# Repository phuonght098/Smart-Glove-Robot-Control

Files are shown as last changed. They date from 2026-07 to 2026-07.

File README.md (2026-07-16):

# Robotic Arm Control via Sensor Glove






✔ Real-time 5 DOF robotic arm teleoperation

✔ Quaternion-based motion estimation

✔ PCA-based automatic anatomical axis calibration

✔ Swing–Twist decomposition for joint angle extraction

✔ Adaptive ZUPT heading drift compensation

✔ ESP-NOW wireless communication

✔ Open-source hardware, firmware, PCB, and 3D models



# Table of Content
1. Introduction
2. Features
3. Hardware
4. Software
5. Getting Started
6. Results
7. Future Work
8. Contact
9. License

# 1. Introduction
This project focuses on the design and fabrication of a 5-degree-of-freedom (5 DOF) robotic arm equipped with a gripper, capable of imitating human arm movements in real-time. Tilt angles and motion data are acquired via a sensor glove equipped with the ICM20948 IMU module.

The project is developed with the aim of researching robotic applications in hazardous environments, enabling remote pick-and-place operations without direct physical intervention.

# 2. Features
🎯 Real-time Control: Low latency operation, accurately tracking and imitating human hand movements.

🧭 Digital Processing with DMP: Utilizes the ICM20948's onboard Digital Motion Processor to calculate Quaternions directly on the sensor, significantly reducing the processing load on the main microcontroller.

⚡ Power Optimization: Features a customized voltage divider circuit and optimized current consumption for better efficiency.

🛠️ Fully Open-source: Provides complete source code, PCB design files, and 3D printing models.

# 3. Hardware

## 3.1 Bill of Materials - BOM
Here is the list of main components used in this project.

| Component  | Qty | 
| :--- | ---: |
| ESP32 | 2 | 
| ICM20948 | 3 | 
| Servo MG996R | 3 | 
| Servo MG90S | 3 |
| PCA9685 | 1 |
| Flex Sensor | 1 |
| Resistor 4.7k | 2 |
| Resistor 10k | 1 |
| Resistor 100k | 1 |
| Resistor 200k | 1 |
| LED | 1 |
| Toggle Switch | 1 |
| Lipo 2s 420mAh | 1 |
| Mini360 | 1 |
| 5v 10A Battery | 1 |
| Ball Bearing 6806ZZ (30x42x7) | 1 |

📌 Note: For the mechanical structure, all .STL files required for 3D printing the robotic arm are provided in the /3D_Models directory.



## 3.2 Wiring & PCB
The schematic and PCB layout files, designed using EasyEDA.com, are located in the /Hardware folder. Due to the I2C address conflict among the ICM20948 sensors (which have a default address of 0x68), we need to connect the AD0 pin of each sensor to Vcc or GND to fix their addresses to either 0x68 or 0x69, as illustrated below.



Below is the wiring diagram of the sensor glove circuit.



A voltage divider circuit is implemented for the flex sensor to read the ADC value on pin D34 of the ESP32. When the flex sensor bends, its resistance changes, which in turn alters the voltage at the junction between the flex sensor and the 10k resistor.

Image of the sensor glove's PCB layout:



## 3.3 3D Printing
Recommended print settings:

Material: PLA / PETG

Infill: > 30%

Layer height: 0.2mm

# 4. Software

## 4.1 Overall System Flowchart
<details>
<summary>📊 System Flowchart</summary>

```mermaid
graph TD
  START([START]) --> INIT1[Initialize ESP32]
  INIT1 --> INIT2[Initialize I2C Bus]
  INIT2 --> INIT3[Initialize 3x ICM20948 IMUs]
  INIT3 --> INIT4[Initialize DMP Quaternion]
  INIT4 --> INIT5[Initialize ESP-NOW]
  INIT5 --> WAIT[Wait for DMP convergence 60s]
  WAIT --> COND{PCA Calibration?}
  
  COND -- Yes --> PCA[PCA Calibration]
  PCA --> ZERO[Zero Calibration]
  ZERO --> MAIN[Main Loop]
  
  COND -- No --> IDLE[Wait for Command]
  IDLE --> MAIN
  
  MAIN --> READ[Read Quaternions from 3 IMUs]
  READ --> SYNC[Synchronize Timestamps]
  SYNC --> NLERP[NLERP Filtering]
  NLERP --> ANAT[Convert to Anatomical Frame]
  ANAT --> CALC[Calculate Joint Angles S1-S5]
  CALC --> MAP[Map to Servo PWM]
  MAP --> SEND[Send via ESP-NOW]
  SEND --> EXEC[Robot Execution]
  EXEC --> READ
```

</details>

## 4.2 Flowchart PCA Calibration
This is the most unique core algorithm of the project for coordinate axis calibration.

<details>
<summary>📊 PCA Calibration </summary>

```mermaid
graph TD
  START([START PCA]) --> NPOSE[N-Pose Posture]
  NPOSE --> GRAV[Measure Gravity Vectors<br>gUpper, gForearm, gHand]
  GRAV --> PCA_S[Shoulder PCA <br> Shoulder Motion]
  PCA_S --> THU_S[Collect Quaternions for 3s]
  THU_S --> DELTA_S[Calculate ΔQuaternion]
  DELTA_S --> COV_S[Create Covariance Matrix]
  COV_S --> POW_S[Power Iteration]
  POW_S --> AXIS_S[Shoulder PCA Axis]
  
  AXIS_S --> PCA_E[Elbow PCA <br> Elbow Motion]
  PCA_E --> THU_E[Collect Quaternions for 3s]
  THU_E --> DELTA_E[Calculate ΔQuaternion]
  DELTA_E --> COV_E[Create Covariance Matrix]
  COV_E --> POW_E[Power Iteration]
  POW_E --> AXIS_E[Elbow PCA Axis]
  
  AXIS_E --> PCA_W[Wrist PCA <br> Wrist Motion]
  PCA_W --> THU_W[Collect Quaternions for 3s]
  THU_W --> DELTA_W[Calculate ΔQuaternion]
  DELTA_W --> COV_W[Create Covariance Matrix]
  COV_W --> POW_W[Power Iteration]
  POW_W --> AXIS_W[Wrist PCA Axis]
  
  AXIS_W --> GRAM[Gram-Schmidt Orthogonalization]
  GRAM --> MOUNT[Create Mount Quaternion]
  MOUNT --> SAVE[Save Q_Mount]
  SAVE --> END([END])
```
</details>

## 4.3 Quaternion Processing Pipeline
This is the main continuous data processing pipeline in the system loop.

<details>
<summary>📊 Quaternion Processing Pipeline </summary>

```mermaid
graph TD
  Q1[/Quaternion Upper/] --> SYNC[Time Synchronization]
  Q2[/Quaternion Forearm/] --> SYNC
  Q3[/Quaternion Hand/] --> SYNC
  
  SYNC --> NLERP[NLERP Filter]
  NLERP --> F1[Q_Upper_Filtered]
  NLERP --> F2[Q_Forearm_Filtered]
  NLERP --> F3[Q_Hand_Filtered]
  
  F1 --> MOUNT[Mount Calibration]
  F2 --> MOUNT
  F3 --> MOUNT
  
  MOUNT --> ANAT[Anatomical Quaternion]
  ANAT --> DRIFT[Drift Compensation]
  DRIFT --> REL[Relative Quaternion]
  
  REL --> J1[Shoulder]
  REL --> J2[Elbow]
  REL --> J3[Wrist]
  
  J1 --> ANGLES[/Joint Angles S1 S2 S3 S4 S5/]
  J2 --> ANGLES
  J3 --> ANGLES

```
</details>

## 4.4 Shoulder Angles
<details>
  
```mermaid
graph TD
  IN[/Q_Shoulder/] --> MAT[Quaternion → Matrix]
  MAT --> R[R_Shoulder Matrix]
  
  R --> S1[S1: atan2<br>-R01, R00]
  R --> S2[S2: asin<br>R02]
  
  S1 --> OUT[/Result: Shoulder Angles/]
  S2 --> OUT

```
</details>

## 4.5 Elbow Angle

<details>

```mermaid
graph TD
  U[/Anat_Upper/] --> INV[Inverse]
  INV --> MUL{X}
  F[/Anat_Forearm/] --> MUL
  
  MUL --> QE[Q_Elbow]
  QE --> DECOMP[Decompose Swing-Twist]
  DECOMP --> TWIST[Twist Component]
  TWIST --> CALC[Calculate Twist Angle<br>2 * atan2]
  
  CALC --> OUT[/S3 Angle <br> Flexion / Extension/]

```
</details>

## 4.6 Wrist Angles

<details>
  
```mermaid
graph TD
  F[/Anat_Forearm/] --> REL[Relative Quaternion]
  H[/Anat_Hand/] --> REL
  
  REL --> QW[Q_Wrist]
  QW --> ST[Swing-Twist Decomposition]
  
  ST --> TWIST[Twist Component]
  TWIST --> S4[/S4 Angle/]
  
  ST --> SWING[Swing Component]
  SWING --> ROT[Rotation Matrix]
  ROT --> ATAN[atan2]
  ATAN --> S5[/S5 Angle/]

```
</details>

# 5. Getting Started
## Prerequisites 

Ensure you have installed Arduino IDE (or PlatformIO) and configured the ESP32 Board Manager. You will also need to install the following libraries via the Arduino Library Manager:

SparkFun 9DoF IMU Breakout - ICM 20948 - Arduino Library (Provides ICM_20948.h and DMP support)

Adafruit PWM Servo Driver Library (Provides Adafruit_PWMServoDriver.h for controlling the servo motors)

📌 Note: The libraries esp_now.h, WiFi.h, and Wire.h are built-in libraries included with the ESP32 board package, so no extra installation is required for them.

## Compilation & Upload 

## Clone this repository

```bash
git clone https://github.com/phuonght098/Smart-Glove-Robot-Control.git
cd Smart-Glove-Robot-Control
```

Upload to Transmitter (Sensor Glove):

Open the Transmitter.ino file located in the /Software/Transmitter folder.

Select your ESP32 board and the correct COM port in the IDE.

Click Upload.

Upload to Receiver (Robotic Arm):

Open the Receiver.ino file located in the /Software/Receiver folder.

Select your ESP32 board and the correct COM port in the IDE.

Click Upload.

Calibration & Usage:

Power on both the robotic arm and the sensor glove.

Keep the glove stationary for the first 60 seconds to allow the ICM20948's DMP (Digital Motion Processor) to converge and the system to complete its initial calibration.

After the DMP converges, you need to calibrate the flex sensor threshold, the PCA motion axes, and the zero posture. 

Once calibrated, the robotic arm will start mirroring the movements of the glove in real-time.

# 6. Results

## 6.1. Transmitter Power Estimation

The table below estimates the current consumption of the sensor glove during continuous operation with ESP-NOW:
| Device | Current Consumption |
| :--- | :---: |
| ESP32 (WiFi + ESP-NOW active) | 150 – 250 mA |
| ICM-20948 #1 | ~3 mA |
| ICM-20948 #2 | ~3 mA |
| ICM-20948 #3 | ~3 mA |
| Flex Sensor | < 1 mA |
| Losses & Overhead | ~100 mA |
| **Total Estimated** | **~260 – 360 mA** |
🔋 Note: With this consumption rate, a standard 8.4V 420mAh LiPo 2S battery can power the glove continuously for approximately 1 to 1.5 hours.

## 6.2 Independent Joint Motion (Cross-Coupling Analysis)


The first experiment evaluates the ability of the proposed algorithm to isolate wrist and elbow motions. Three sequential phases were performed:

Phase 1: Static posture
Phase 2: Elbow flexion only
Phase 3: Wrist pronation/supination only

During elbow flexion, the elbow angle (S3) increased smoothly from approximately 0° to 85°, while the wrist angles (S4 and S5) remained close to zero, exhibiting only small fluctuations below approximately ±5°.

Conversely, during wrist rotation, S4 increased to approximately 80°, whereas the elbow angle (S3) remained almost constant, indicating that elbow estimation was not affected by wrist motion.

These results demonstrate that the proposed quaternion-based biomechanical decomposition successfully separates rotational components between adjacent joints. Compared with conventional Euler-angle methods, which frequently suffer from cross-axis interference, the proposed Swing–Twist decomposition significantly reduces motion coupling between the elbow and wrist.

## 6.3. Elbow Joint Angle Accuracy


The second experiment compares the elbow flexion angle estimated by the proposed IMU system against a reference trajectory obtained using video-based motion capture.

The two curves exhibit nearly identical profiles throughout the complete flexion-extension cycle. Both systems capture:

the beginning of elbow flexion,
the constant-angle holding period,
and the return to the neutral position.

Only a small temporal delay (approximately 150 ms) can be observed, which mainly originates from the IMU sensor output rate, quaternion filtering, and wireless transmission latency.

Apart from this minor delay, the amplitude and trajectory closely match the reference measurements, indicating that the proposed algorithm provides accurate real-time joint angle estimation suitable for robotic teleoperation applications.

## 6.4. Heading Drift Compensation (ZUPT)


Long-term orientation drift caused by gyroscope bias is a common limitation of inertial measurement systems. To evaluate the effectiveness of the proposed Zero Velocity Update (ZUPT) compensation, the user maintained a static posture for approximately 10 seconds.

Without drift compensation, the estimated heading error gradually accumulated from 0° to approximately 15°, despite no actual movement.

When the proposed ZUPT-based correction was enabled, the estimated error remained close to 0°, with only minor fluctuations of approximately ±1°.

These results confirm that the proposed adaptive drift compensation effectively suppresses low-frequency heading drift during stationary periods while avoiding sudden orientation corrections that could disturb robot motion.

## 6.5. Gimbal Lock Elimination


The final experiment investigates the behavior of the orientation representation near singular configurations.

The arm was gradually raised until approaching 90°, where conventional Euler-angle representations typically experience gimbal lock.

The Euler-angle curve exhibited significant oscillations and unstable spikes around the singular posture, despite the arm remaining almost stationary.

In contrast, the quaternion-based orientation remained smooth and continuous throughout the entire movement, showing no observable discontinuities or instability.

This experiment demonstrates one of the major advantages of quaternion-based orientation estimation. Since quaternions do not rely on sequential rotations, they avoid the singularity problem inherent to Euler angles and provide robust orientation tracking over the full workspace.

## 6.6. Overall Discussion

The experimental results verify the effectiveness of the proposed motion-capture pipeline from multiple aspects.

The biomechanical joint decomposition effectively minimizes cross-coupling between neighboring joints.
Quaternion-based orientation estimation accurately reproduces elbow motion with only a small latency relative to camera-based measurements.
The adaptive ZUPT algorithm successfully compensates gyroscope heading drift during stationary periods.
Quaternion representation completely eliminates the instability associated with Euler-angle singularities.

Overall, the proposed system demonstrates stable real-time performance and provides sufficiently accurate joint-angle estimation for robotic arm teleoperation while maintaining computational efficiency on the ESP32 platform.

# 7. Future Work

🚧 Limitations: Servo motor lifting capacity is limited; the system can be susceptible to signal interference in highly metallic environments.

🚀 Future Directions:

Replace Servo motors with BLDC motors combined with Encoders to increase accuracy and payload capacity.

Integrate Force Feedback sensors into the glove so the user can "feel" the objects being grabbed.

# 8. Contact

Author: Huynh Thanh Phuong

Email: phuong0342098446@gmail

LinkedIn: https://www.linkedin.com/in/phuonght098/

If you find this project helpful, please consider giving it a ⭐ (Star) on GitHub! Thank you!

# 9. License

This project is licensed under the MIT License.

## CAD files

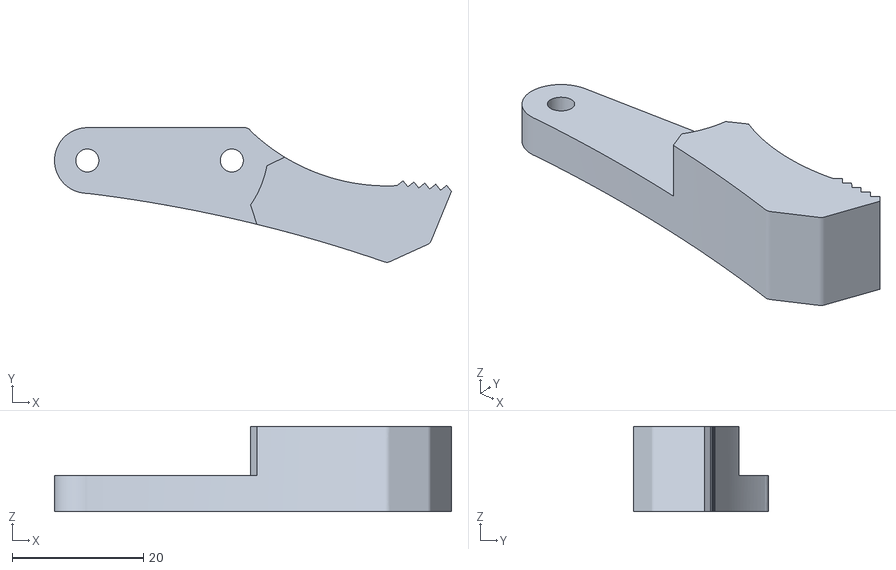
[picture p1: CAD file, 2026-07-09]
3D_Model/gripper_part_right.stl
60.4 x 20.5 x 13.0

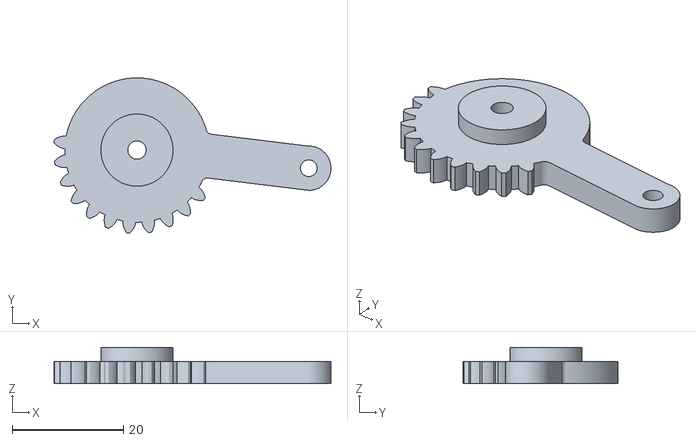
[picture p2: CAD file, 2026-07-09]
3D_Model/gripper_gear_right.stl
49.9 x 27.9 x 6.50

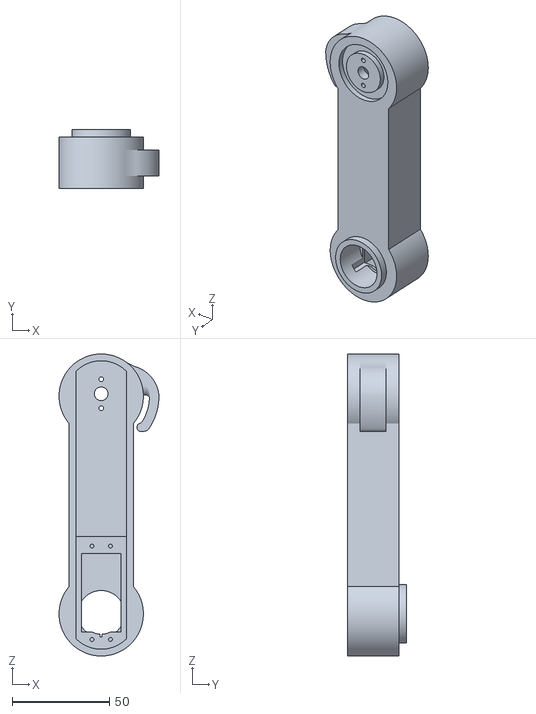
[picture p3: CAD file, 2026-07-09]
3D_Model/arm_link_1.stl
51.3 x 30.5 x 155.2

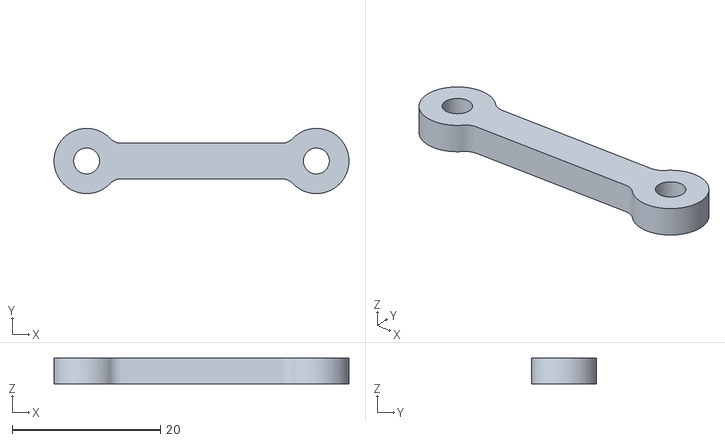
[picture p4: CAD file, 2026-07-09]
3D_Model/gripper_link.stl
39.8 x 8.80 x 3.50

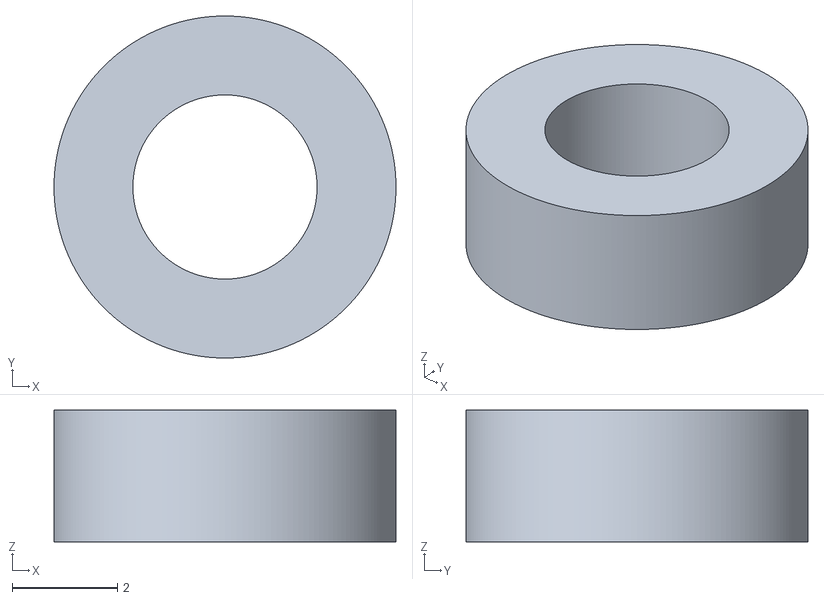
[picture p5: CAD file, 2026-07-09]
3D_Model/gripper_sleeve.stl
6.50 x 6.50 x 2.50

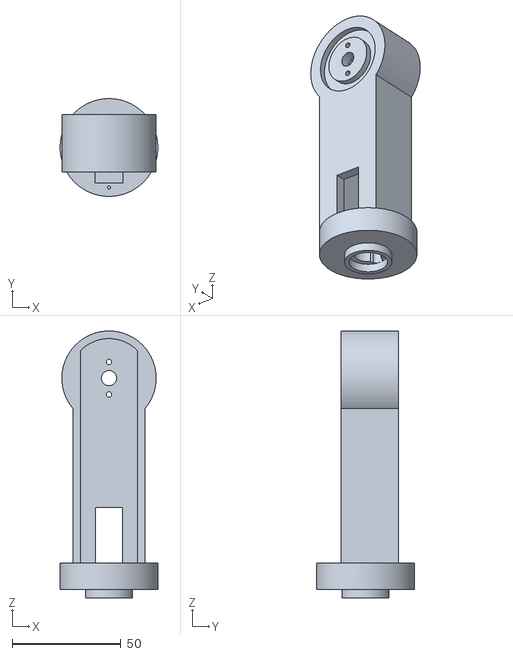
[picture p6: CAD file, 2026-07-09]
3D_Model/arm_link_2.stl
44.9 x 44.9 x 122.7

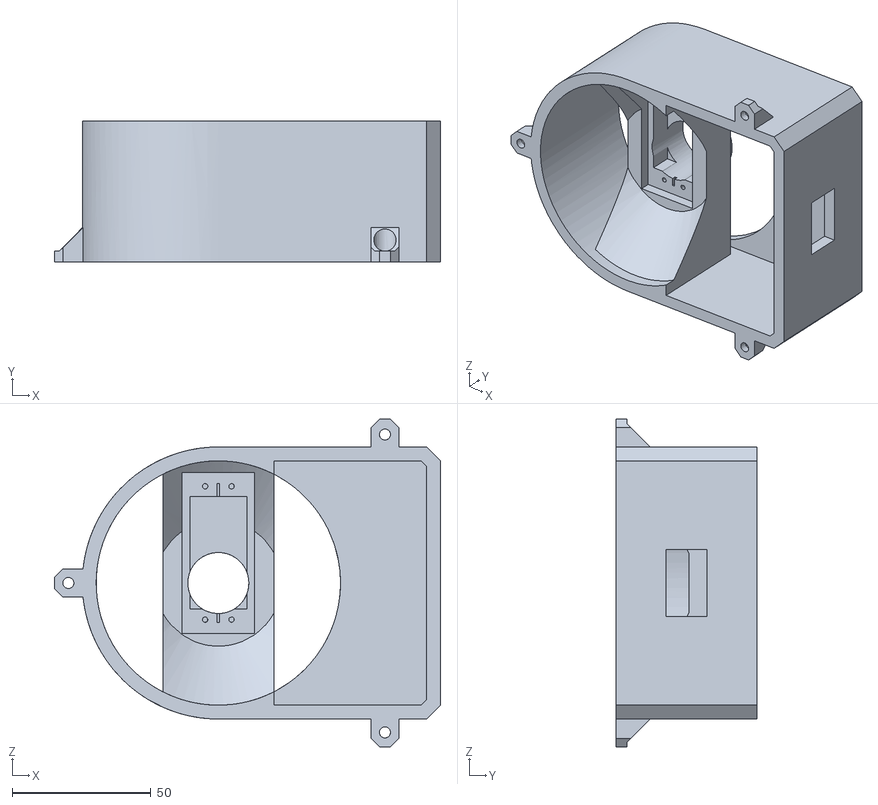
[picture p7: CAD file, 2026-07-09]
3D_Model/base.stl
139.0 x 50.9 x 118.0

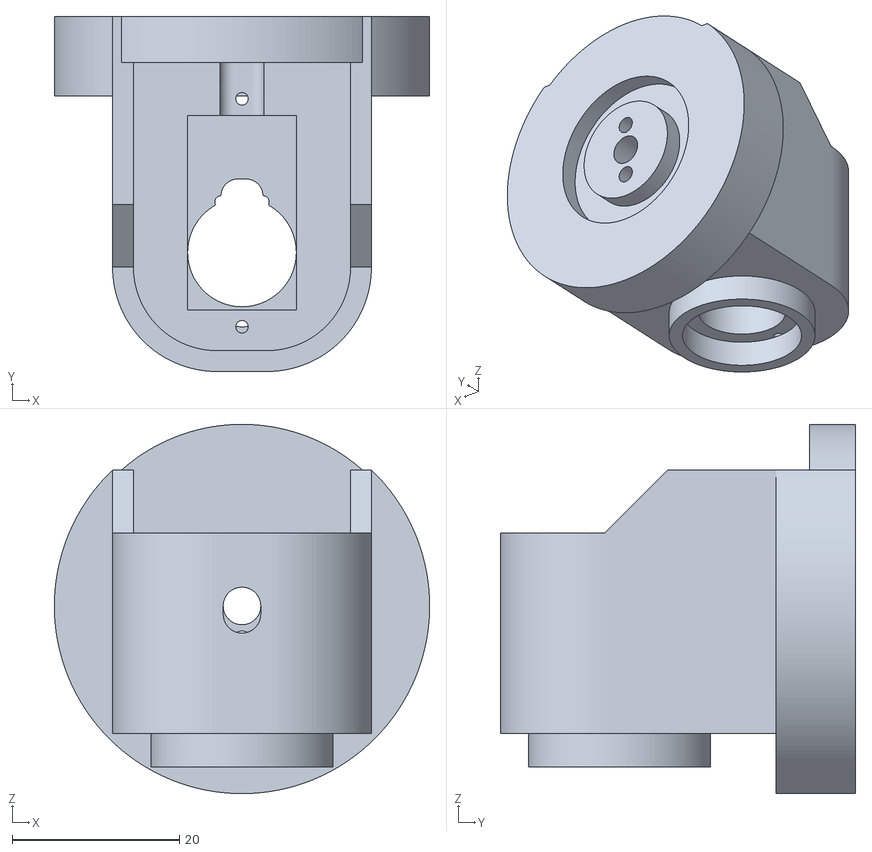
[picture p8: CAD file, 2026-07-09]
3D_Model/arm_link_3.stl
44.9 x 42.5 x 44.2

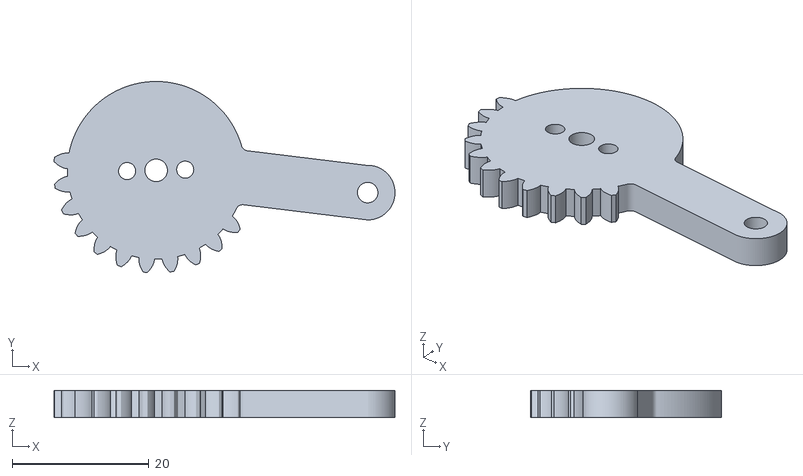
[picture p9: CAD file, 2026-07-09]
3D_Model/gripper_gear_left.stl
49.9 x 27.9 x 4.00

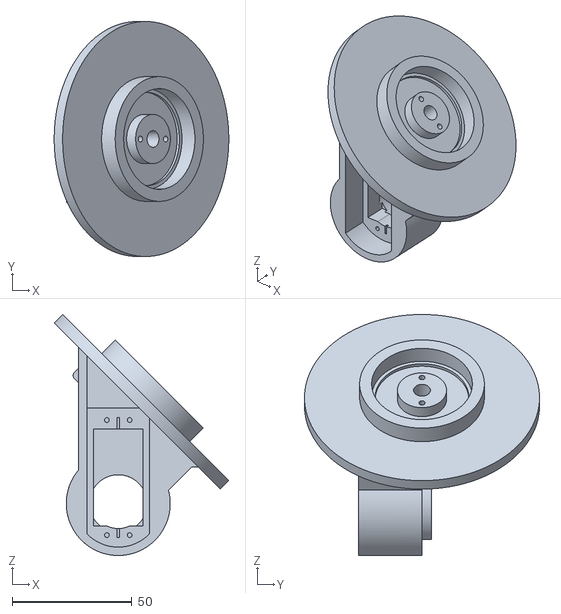
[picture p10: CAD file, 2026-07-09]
3D_Model/base_link_upper.stl
72.8 x 98.0 x 100.5

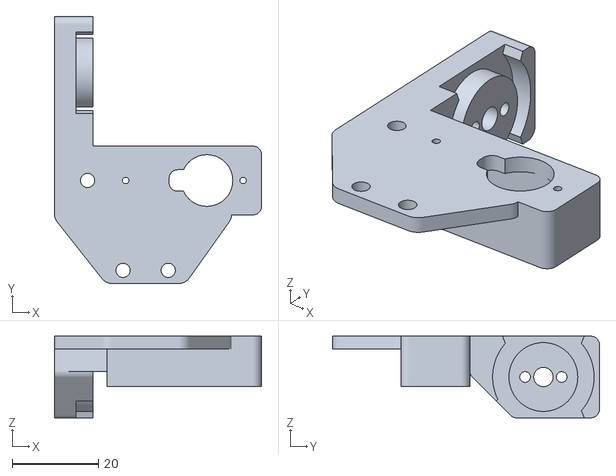
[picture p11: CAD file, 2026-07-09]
3D_Model/gripper_base.stl
48.2 x 62.1 x 19.0

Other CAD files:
3D_Model/gripper_part_left.stl

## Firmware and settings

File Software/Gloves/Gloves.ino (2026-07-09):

/**
 * DỰ ÁN: GĂNG TAY ĐIỀU KHIỂN ROBOT - PIPELINE 10.4 (ADAPTIVE ORTHOGONAL ZUPT EDITION)
 * Cải tiến:
 * 1. Trực chuẩn hóa Vai (S1, S2) bằng Gram-Schmidt.
 * 2. Bộ lọc trạng thái EMA ZUPT chống rung/nhiễu vi cấp.
 * 3. Tăng tốc độ bù Drift Heading khi ở trạng thái tĩnh.
 * 4. Phân ly động học Cổ tay hoàn toàn khỏi Cẳng tay thông qua ZUPT Gating.
 */

#include <Wire.h>
#ifndef ICM_20948_USE_DMP
#define ICM_20948_USE_DMP
#endif
#include "ICM_20948.h"
#include <esp_now.h>
#include <WiFi.h>

// ==============================================================================
// ĐỊNH NGHĨA CHÂN GIAO TIẾP
// ==============================================================================
#define I2C_BUS0_SDA    21
#define I2C_BUS0_SCL    22
#define I2C_BUS1_SDA    19
#define I2C_BUS1_SCL    18
#define LED_PIN         32
#define FLEX_PIN        34
#define BOOT_BUTTON_PIN 0

#define I2CBus0 Wire
#define I2CBus1 Wire1
#define AD0_VCC 1
#define AD0_GND 0

// ==============================================================================
// CẤU TRÚC DỮ LIỆU
// ==============================================================================
struct Quat { float w, x, y, z; };
struct Vec3 { float x, y, z; }; 
struct Mat3x3 { float m[3][3]; };
struct JointMap { float rawMin, rawMax, servoMin, servoMax; };

JointMap mapS1 = { -90.0f,  90.0f,  10.0f, 150.0f }; 
JointMap mapS2 = { -90.0f,  90.0f,  65.0f, 135.0f }; 
JointMap mapS3 = {   0.0f, 140.0f,   0.0f,  90.0f }; 
JointMap mapS4 = {-150.0f,  85.0f,  60.0f, 140.0f }; 
JointMap mapS5 = { -95.0f,  35.0f,  40.0f, 170.0f }; 

const Vec3 ANAT_AXIS_X = {1.0f, 0.0f, 0.0f}; 
const Vec3 ANAT_AXIS_Y = {0.0f, 1.0f, 0.0f}; 
const Vec3 ANAT_AXIS_Z = {0.0f, 0.0f, 1.0f}; 

// ==============================================================================
// TOÁN HỌC KHÔNG GIAN 3D
// ==============================================================================
namespace Math3D {
    Quat quatInverse(Quat q) { return {q.w, -q.x, -q.y, -q.z}; }
    float quatDot(Quat q1, Quat q2) { return q1.w*q2.w + q1.x*q2.x + q1.y*q2.y + q1.z*q2.z; }
    float vecDot(Vec3 v1, Vec3 v2) { return v1.x*v2.x + v1.y*v2.y + v1.z*v2.z; }
    Vec3 vecCross(Vec3 a, Vec3 b) { return { a.y*b.z - a.z*b.y, a.z*b.x - a.x*b.z, a.x*b.y - a.y*b.x }; }
    Vec3 vecScale(Vec3 v, float s) { return {v.x * s, v.y * s, v.z * s}; }
    float vecMagnitude(Vec3 v) { return sqrt(v.x*v.x + v.y*v.y + v.z*v.z); }
    
    void vecNormalize(Vec3 &v) {
        float n = vecMagnitude(v);
        if (n > 1e-6f) { v.x /= n; v.y /= n; v.z /= n; } else { v = {0,0,0}; }
    }
    
    void normalize(Quat &q) {
        float n = sqrt(q.w*q.w + q.x*q.x + q.y*q.y + q.z*q.z);
        if (n > 1e-6f) { q.w /= n; q.x /= n; q.y /= n; q.z /= n; } else { q = {1,0,0,0}; }
    }

    Quat quatMultiply(Quat q1, Quat q2) {
        Quat res;
        res.w = q1.w*q2.w - q1.x*q2.x - q1.y*q2.y - q1.z*q2.z;
        res.x = q1.w*q2.x + q1.x*q2.w + q1.y*q2.z - q1.z*q2.y;
        res.y = q1.w*q2.y - q1.x*q2.z + q1.y*q2.w + q1.z*q2.x;
        res.z = q1.w*q2.z + q1.x*q2.y - q1.y*q2.x + q1.z*q2.w;
        normalize(res); return res;
    }

    Vec3 rotateVector(Vec3 v, Quat q) {
        Quat vQ = {0, v.x, v.y, v.z};
        Quat res = quatMultiply(quatMultiply(q, vQ), quatInverse(q));
        return {res.x, res.y, res.z};
    }

    Quat nlerp(Quat qPrev, Quat qNew, float t) {
        if (quatDot(qPrev, qNew) < 0.0f) qNew = {-qNew.w, -qNew.x, -qNew.y, -qNew.z}; 
        Quat res = { qPrev.w + t*(qNew.w - qPrev.w), qPrev.x + t*(qNew.x - qPrev.x),
                     qPrev.y + t*(qNew.y - qPrev.y), qPrev.z + t*(qNew.z - qPrev.z) };
        normalize(res); return res;
    }

    Mat3x3 quatToMatrix(Quat q) {
        Mat3x3 m;
        float xx = q.x*q.x, yy = q.y*q.y, zz = q.z*q.z;
        float xy = q.x*q.y, xz = q.x*q.z, yz = q.y*q.z;
        float wx = q.w*q.x, wy = q.w*q.y, wz = q.w*q.z;
        m.m[0][0] = 1.0f - 2.0f*(yy + zz); m.m[0][1] = 2.0f*(xy - wz);        m.m[0][2] = 2.0f*(xz + wy);
        m.m[1][0] = 2.0f*(xy + wz);        m.m[1][1] = 1.0f - 2.0f*(xx + zz); m.m[1][2] = 2.0f*(yz - wx);
        m.m[2][0] = 2.0f*(xz - wy);        m.m[2][1] = 2.0f*(yz + wx);        m.m[2][2] = 1.0f - 2.0f*(xx + yy);
        return m;
    }

    Quat matrixToQuat(Mat3x3 m) {
        Quat q;
        float tr = m.m[0][0] + m.m[1][1] + m.m[2][2];
        if (tr > 0.0f) {
            float S = sqrt(tr + 1.0f) * 2.0f;
            q.w = 0.25f * S; q.x = (m.m[2][1] - m.m[1][2]) / S;
            q.y = (m.m[0][2] - m.m[2][0]) / S; q.z = (m.m[1][0] - m.m[0][1]) / S;
        } else if ((m.m[0][0] > m.m[1][1]) && (m.m[0][0] > m.m[2][2])) {
            float S = sqrt(1.0f + m.m[0][0] - m.m[1][1] - m.m[2][2]) * 2.0f;
            q.w = (m.m[2][1] - m.m[1][2]) / S; q.x = 0.25f * S;
            q.y = (m.m[0][1] + m.m[1][0]) / S; q.z = (m.m[0][2] + m.m[2][0]) / S;
        } else if (m.m[1][1] > m.m[2][2]) {
            float S = sqrt(1.0f + m.m[1][1] - m.m[0][0] - m.m[2][2]) * 2.0f;
            q.w = (m.m[0][2] - m.m[2][0]) / S; q.x = (m.m[0][1] + m.m[1][0]) / S;
            q.y = 0.25f * S; q.z = (m.m[1][2] + m.m[2][1]) / S;
        } else {
            float S = sqrt(1.0f + m.m[2][2] - m.m[0][0] - m.m[1][1]) * 2.0f;
            q.w = (m.m[1][0] - m.m[0][1]) / S; q.x = (m.m[0][2] + m.m[2][0]) / S;
            q.y = (m.m[1][2] + m.m[2][1]) / S; q.z = 0.25f * S;
        }
        normalize(q); return q;
    }

    Quat build3DOFMountQuat_GramSchmidt(Vec3 vHingePCA, Vec3 vGravityNPose, bool isHingeZ, const char* jointName = "") {
        vecNormalize(vHingePCA); vecNormalize(vGravityNPose);
        Mat3x3 R; Vec3 eX, eY, eZ; 
        if (isHingeZ) {
            eZ = vHingePCA;
            eX = vecCross(vecScale(vGravityNPose, -1.0f), eZ);
            if (vecMagnitude(eX) < 0.05f) eX = vecCross(ANAT_AXIS_X, eZ);
            vecNormalize(eX); eY = vecCross(eZ, eX); vecNormalize(eY);
        } else {
            eY = vHingePCA;
            eX = vecCross(eY, vGravityNPose);
            if (vecMagnitude(eX) < 0.05f) eX = vecCross(eY, ANAT_AXIS_Z);
            vecNormalize(eX); eZ = vecCross(eX, eY); vecNormalize(eZ);
        }
        R.m[0][0]=eX.x; R.m[0][1]=eY.x; R.m[0][2]=eZ.x;
        R.m[1][0]=eX.y; R.m[1][1]=eY.y; R.m[1][2]=eZ.y;
        R.m[2][0]=eX.z; R.m[2][1]=eY.z; R.m[2][2]=eZ.z;
        return matrixToQuat(R);
    }

    Quat buildHandMount_GramSchmidt(Vec3 vTwist, Vec3 vSwing, const char* jointName = "") {
        vecNormalize(vTwist);
        float proj = vecDot(vSwing, vTwist);
        Vec3 eX = { vSwing.x - proj*vTwist.x, vSwing.y - proj*vTwist.y, vSwing.z - proj*vTwist.z };
        vecNormalize(eX);
        Vec3 eY = vTwist; 
        Vec3 eZ = vecCross(eX, eY); vecNormalize(eZ);
        Mat3x3 R;
        R.m[0][0]=eX.x; R.m[0][1]=eY.x; R.m[0][2]=eZ.x;
        R.m[1][0]=eX.y; R.m[1][1]=eY.y; R.m[1][2]=eZ.y;
        R.m[2][0]=eX.z; R.m[2][1]=eY.z; R.m[2][2]=eZ.z;
        return matrixToQuat(R);
    }

    void decomposeSwingTwist(Quat q, Vec3 axis, Quat &swing, Quat &twist) {
        Vec3 v = {q.x, q.y, q.z};
        float proj = vecDot(v, axis);
        Vec3 vTwist = vecScale(axis, proj);
        twist = {q.w, vTwist.x, vTwist.y, vTwist.z};
        normalize(twist);
        swing = quatMultiply(q, quatInverse(twist));
    }
    
    float getTwistAngle(Quat qTwist, Vec3 axis) {
        float angle = 2.0f * atan2(sqrt(qTwist.x*qTwist.x + qTwist.y*qTwist.y + qTwist.z*qTwist.z), qTwist.w) * 180.0f / PI;
        if (vecDot({qTwist.x, qTwist.y, qTwist.z}, axis) < 0.0f) angle = -angle;
        return angle;
    }
}

// ==============================================================================
// GIAO TIẾP DMP & HELPER
// ==============================================================================
void printQuat(const char* label, Quat q) { Serial.printf("%-20s : [W: %6.3f | X: %6.3f | Y: %6.3f | Z: %6.3f]\n", label, q.w, q.x, q.y, q.z); }
void printVec(const char* label, Vec3 v) { Serial.printf("%-20s : [X: %6.3f | Y: %6.3f | Z: %6.3f]\n", label, v.x, v.y, v.z); }

Quat dmpQuat9ToBodyQuat(icm_20948_DMP_data_t &data) {
    Quat q; const float Q30_SCALE = 1.0f / 1073741824.0f; 
    q.x = ((int32_t)data.Quat9.Data.Q1) * Q30_SCALE;
    q.y = ((int32_t)data.Quat9.Data.Q2) * Q30_SCALE;
    q.z = ((int32_t)data.Quat9.Data.Q3) * Q30_SCALE;
    q.w = ((int32_t)data.Quat9.Data.Q1 + 0) ? sqrtf(constrain(1.0f - (q.x*q.x + q.y*q.y + q.z*q.z), 0.0f, 1.0f)) : 1.0f;
    if (data.header & DMP_header_bitmap_Quat9) q.w = ((int32_t)data.Quat9.Data.Q1 == 0 && q.x == 0 && q.y == 0 && q.z == 0) ? 1.0f : sqrtf(constrain(1.0f - (q.x*q.x + q.y*q.y + q.z*q.z), 0.0f, 1.0f));
    Math3D::normalize(q); return q;
}

void initDMPDevice(ICM_20948_I2C &imu, TwoWire &wirePort, uint8_t ad0_val) {
    imu.begin(wirePort, ad0_val);
    if (imu.status != ICM_20948_Stat_Ok) return;
    imu.initializeDMP(); imu.enableDMPSensor(INV_ICM20948_SENSOR_ORIENTATION);
    imu.setDMPODRrate(DMP_ODR_Reg_Quat9, 1); imu.enableFIFO();
    imu.enableDMP(); imu.resetDMP(); imu.resetFIFO();
}

// ==============================================================================
// BIẾN TOÀN CỤC
// ==============================================================================
ICM_20948_I2C imuHand, imuForearm, imuUpperArm;
Quat rawUpper, rawForearm, rawHand, filteredUpper, filteredForearm, filteredHand;
Quat Q_Mount_Upper, Q_Mount_Forearm, Q_Mount_Hand;
Quat Home_Anat_Upper, Home_Anat_Forearm, Home_Anat_Hand;
Quat Home_Rel_Elbow, Home_Rel_Wrist;
Quat Q_DriftRel_Shoulder, Q_DriftRel_Elbow, Q_DriftRel_Wrist;

Vec3 dynAxis_S1_Yaw = ANAT_AXIS_Z;    
Vec3 dynAxis_S2_Pitch = ANAT_AXIS_Y;  
Vec3 dynAxis_S3_Elbow = ANAT_AXIS_Z;  
Vec3 dynAxis_S4_Twist = ANAT_AXIS_Y;  
Vec3 dynAxis_S5_Swing = ANAT_AXIS_X;  

// EMA ZUPT States
float emaGyrMagU = 0.0f, emaGyrMagF = 0.0f, emaGyrMagH = 0.0f;
float emaAccMagU = 1000.0f, emaAccMagF = 1000.0f;

float flexGripThreshold = 2700.0f; 
float flexReleaseThreshold = 2650.0f;
bool firstFrameAfterCalib = true; bool systemCalibrated = false; 

unsigned long lastSendTime = 0, lastDebugTime = 0, staticStartTime = 0;
float currentS1=0, currentS2=0, currentS3=0, currentS4=0, currentS5=0, currentS6=0;
const float DEADBAND_DEG = 1.2f, Q_FILTER_ALPHA = 0.4f;

typedef struct { float S1, S2, S3, S4, S5, S6; int flex; } RobotCommand;
RobotCommand txData;
uint8_t rxMacAddress[] = {0xFF, 0xFF, 0xFF, 0xFF, 0xFF, 0xFF};

unsigned long tHand = 0, tForearm = 0, tUpper = 0;
Quat rawHandBuf, rawForearmBuf, rawUpperBuf;

// ==============================================================================
// ĐỌC DỮ LIỆU ĐỒNG BỘ & CẬP NHẬT ZUPT STATES
// ==============================================================================
bool fetchSynchronizedIMUData() {
    unsigned long now = millis();
    if (imuHand.dataReady()) {
        icm_20948_DMP_data_t dmp; imuHand.readDMPdataFromFIFO(&dmp);
        if (imuHand.status == ICM_20948_Stat_Ok && (dmp.header & DMP_header_bitmap_Quat9)) { rawHandBuf = dmpQuat9ToBodyQuat(dmp); tHand = now; }
    }
    if (imuForearm.dataReady()) {
        icm_20948_DMP_data_t dmp; imuForearm.readDMPdataFromFIFO(&dmp);
        if (imuForearm.status == ICM_20948_Stat_Ok && (dmp.header & DMP_header_bitmap_Quat9)) { rawForearmBuf = dmpQuat9ToBodyQuat(dmp); tForearm = now; }
    }
    if (imuUpperArm.dataReady()) {
        icm_20948_DMP_data_t dmp; imuUpperArm.readDMPdataFromFIFO(&dmp);
        if (imuUpperArm.status == ICM_20948_Stat_Ok && (dmp.header & DMP_header_bitmap_Quat9)) { rawUpperBuf = dmpQuat9ToBodyQuat(dmp); tUpper = now; }
    }

    if (tHand > 0 && tForearm > 0 && tUpper > 0) {
        unsigned long maxT = max(tHand, max(tForearm, tUpper));
        unsigned long minT = min(tHand, min(tForearm, tUpper));
        if ((maxT - minT) <= 25) {
            static unsigned long lastValidSync = 0;
            if (maxT != lastValidSync) {
                lastValidSync = maxT;
                rawHand = rawHandBuf; rawForearm = rawForearmBuf; rawUpper = rawUpperBuf;
                if (firstFrameAfterCalib) {
                    filteredHand = rawHand; filteredForearm = rawForearm; filteredUpper = rawUpper;
                } else {
                    filteredHand    = Math3D::nlerp(filteredHand,    rawHand,    Q_FILTER_ALPHA);
                    filteredForearm = Math3D::nlerp(filteredForearm, rawForearm, Q_FILTER_ALPHA);
                    filteredUpper   = Math3D::nlerp(filteredUpper,   rawUpper,   Q_FILTER_ALPHA);
                }

                // Cập nhật EMA ZUPT Filter
                imuUpperArm.getAGMT(); imuForearm.getAGMT(); imuHand.getAGMT();
                float gyrU = sqrtf(pow(imuUpperArm.gyrX(),2) + pow(imuUpperArm.gyrY(),2) + pow(imuUpperArm.gyrZ(),2));
                float gyrF = sqrtf(pow(imuForearm.gyrX(),2)  + pow(imuForearm.gyrY(),2)  + pow(imuForearm.gyrZ(),2));
                float gyrH = sqrtf(pow(imuHand.gyrX(),2)     + pow(imuHand.gyrY(),2)     + pow(imuHand.gyrZ(),2));
                emaGyrMagU = 0.2f * gyrU + 0.8f * emaGyrMagU;
                emaGyrMagF = 0.2f * gyrF + 0.8f * emaGyrMagF;
                emaGyrMagH = 0.2f * gyrH + 0.8f * emaGyrMagH;

                float accU = sqrtf(pow(imuUpperArm.accX(),2) + pow(imuUpperArm.accY(),2) + pow(imuUpperArm.accZ(),2));
                float accF = sqrtf(pow(imuForearm.accX(),2)  + pow(imuForearm.accY(),2)  + pow(imuForearm.accZ(),2));
                emaAccMagU = 0.2f * accU + 0.8f * emaAccMagU;
                emaAccMagF = 0.2f * accF + 0.8f * emaAccMagF;

                return true; 
            }
        }
    }
    return false;
}

Vec3 getSensorGravityVector(ICM_20948_I2C &imu) {
    ICM_20948_AGMT_t agmt = imu.getAGMT();
    Vec3 g = { (float)agmt.acc.axes.x, (float)agmt.acc.axes.y, (float)agmt.acc.axes.z };
    Math3D::vecNormalize(g); return g;
}

bool checkZUPT_ZeroVelocityGate() {
    // Ngưỡng ZUPT tích hợp bộ lọc EMA chống gai nhiễu (Adaptive approach)
    if (emaGyrMagU > 12.0f || emaGyrMagF > 12.0f || emaGyrMagH > 15.0f) return false;
    if (abs(emaAccMagU - 1000.0f) > 180.0f || abs(emaAccMagF - 1000.0f) > 180.0f) return false;
    return true;
}
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
void loop() {
    static unsigned long buttonPressStart = 0; static bool isButtonPressed = false;
    bool currentButtonState = (digitalRead(BOOT_BUTTON_PIN) == LOW);
    if (currentButtonState && !isButtonPressed) { isButtonPressed = true; buttonPressStart = millis(); } 
    else if (!currentButtonState && isButtonPressed) {
        isButtonPressed = false;
        if (millis() - buttonPressStart >= 2000) runFullAnatomical3DOFMountCalibration();
        else if (millis() - buttonPressStart >= 50) runZeroCalibrationRoutine();
    }

    if (Serial.available()) {
        char c = Serial.read();
        if (c == 'f' || c == 'F') { runFullAnatomical3DOFMountCalibration(); while(Serial.available()) Serial.read(); }
        else if (c == 'c' || c == 'C') { runZeroCalibrationRoutine(); while(Serial.available()) Serial.read(); }
    }

    if (fetchSynchronizedIMUData() && systemCalibrated) {
        
        Quat Anat_U = Math3D::quatMultiply(filteredUpper,   Q_Mount_Upper);
        Quat Anat_F = Math3D::quatMultiply(filteredForearm, Q_Mount_Forearm);
        Quat Anat_H = Math3D::quatMultiply(filteredHand,    Q_Mount_Hand);

        handleRelativeHeadingDriftCompensation(Anat_U, Anat_F, Anat_H);

        Quat Corrected_U = Math3D::quatMultiply(Anat_U, Math3D::quatInverse(Q_DriftRel_Shoulder));
        Quat Q_Shoulder  = Math3D::quatMultiply(Math3D::quatInverse(Home_Anat_Upper), Corrected_U);

        Quat rawRelElbow = Math3D::quatMultiply(Math3D::quatInverse(Anat_U), Anat_F);
        Quat Q_Elbow     = Math3D::quatMultiply(Math3D::quatInverse(Q_DriftRel_Elbow), Math3D::quatMultiply(Math3D::quatInverse(Home_Rel_Elbow), rawRelElbow));

        Quat rawRelWrist = Math3D::quatMultiply(Math3D::quatInverse(Anat_F), Anat_H);
        Quat Q_Wrist     = Math3D::quatMultiply(Math3D::quatInverse(Q_DriftRel_Wrist), Math3D::quatMultiply(Math3D::quatInverse(Home_Rel_Wrist), rawRelWrist));

        // --- CASCADED KINEMATICS TRỰC GIAO ---
        Quat residual, twist;

        // Vai
        Math3D::decomposeSwingTwist(Q_Shoulder, dynAxis_S1_Yaw, residual, twist);
        float rawS1 = Math3D::getTwistAngle(twist, dynAxis_S1_Yaw);
        Math3D::decomposeSwingTwist(residual, dynAxis_S2_Pitch, residual, twist);
        float rawS2 = Math3D::getTwistAngle(twist, dynAxis_S2_Pitch);

        // Khuỷu
        Math3D::decomposeSwingTwist(Q_Elbow, dynAxis_S3_Elbow, residual, twist);
        float rawS3 = Math3D::getTwistAngle(twist, dynAxis_S3_Elbow);

                // Cổ tay
        Math3D::decomposeSwingTwist(Q_Wrist, dynAxis_S4_Twist, residual, twist);
        float tempS4 = Math3D::getTwistAngle(twist, dynAxis_S4_Twist);
        Math3D::decomposeSwingTwist(residual, dynAxis_S5_Swing, residual, twist);
        float tempS5 = Math3D::getTwistAngle(twist, dynAxis_S5_Swing);

                // --- ZUPT MOTION GATING & FLEX LOGIC ---
        bool isArmMoving = (emaGyrMagU > 15.0f || emaGyrMagF > 15.0f);
        static float frozen_S4 = 0.0f;
        static float frozen_S5 = 0.0f;
        static bool isGripping = false;

        int flexRaw = analogRead(FLEX_PIN);
        static float smoothedFlex = flexRaw;
        smoothedFlex = 0.15f * flexRaw + 0.85f * smoothedFlex;

        if (smoothedFlex > flexGripThreshold) isGripping = true;
        else if (smoothedFlex < flexReleaseThreshold) isGripping = false;

        float rawS4 = frozen_S4;
        float rawS5 = frozen_S5;

        if (!isArmMoving) {
            // Chỉ decomposition khi tay dừng
            Math3D::decomposeSwingTwist(Q_Wrist, dynAxis_S4_Twist, residual, twist);
            float tempS4 = Math3D::getTwistAngle(twist, dynAxis_S4_Twist);
            Math3D::decomposeSwingTwist(residual, dynAxis_S5_Swing, residual, twist);
            float tempS5 = Math3D::getTwistAngle(twist, dynAxis_S5_Swing);

            if (isGripping) {
                rawS4 = frozen_S4;
                rawS5 = frozen_S5;
            } else {
                float delta4 = fabs(tempS4 - frozen_S4);
                float delta5 = fabs(tempS5 - frozen_S5);
                if (delta4 > delta5) {
                    rawS4 = tempS4;
                    rawS5 = frozen_S5;
                } else {
                    rawS4 = frozen_S4;
                    rawS5 = tempS5;
                }
            }
            frozen_S4 = rawS4;
            frozen_S5 = rawS5;
        }

        float rawS6 = isGripping ? 10.0f : 50.0f;

        clampBiomechanicalLimits(rawS1, rawS2, rawS3, rawS4, rawS5);

        // --- GỬI ĐIỀU KHIỂN ---
        if (millis() - lastSendTime > 20) {
            lastSendTime = millis();

            float t1 = constrain(mapFloat(rawS1, mapS1.rawMin, mapS1.rawMax, mapS1.servoMin, mapS1.servoMax), mapS1.servoMin, mapS1.servoMax);
            float t2 = constrain(mapFloat(rawS2, mapS2.rawMin, mapS2.rawMax, mapS2.servoMin, mapS2.servoMax), mapS2.servoMin, mapS2.servoMax);
            float t3 = constrain(mapFloat(rawS3, mapS3.rawMin, mapS3.rawMax, mapS3.servoMin, mapS3.servoMax), mapS3.servoMin, mapS3.servoMax);
            float t4 = constrain(mapFloat(rawS4, mapS4.rawMin, mapS4.rawMax, mapS4.servoMin, mapS4.servoMax), mapS4.servoMin, mapS4.servoMax);
            float t5 = constrain(mapFloat(rawS5, mapS5.rawMin, mapS5.rawMax, mapS5.servoMin, mapS5.servoMax), mapS5.servoMin, mapS5.servoMax);

            if (firstFrameAfterCalib) {
                currentS1 = t1; currentS2 = t2; currentS3 = t3; currentS4 = t4; currentS5 = t5; currentS6 = rawS6;
                firstFrameAfterCalib = false;
            } else {
                currentS1 = applyDeadband(t1, currentS1, DEADBAND_DEG); currentS2 = applyDeadband(t2, currentS2, DEADBAND_DEG);
                currentS3 = applyDeadband(t3, currentS3, DEADBAND_DEG); currentS4 = applyDeadband(t4, currentS4, DEADBAND_DEG);
                currentS5 = applyDeadband(t5, currentS5, DEADBAND_DEG); currentS6 = applyDeadband(rawS6, currentS6, DEADBAND_DEG);
            }

            txData.S1 = currentS2; txData.S2 = currentS1; txData.S3 = currentS3;
            txData.S4 = currentS4; txData.S5 = currentS5; txData.S6 = currentS6;
            esp_now_send(rxMacAddress, (uint8_t*)&txData, sizeof(txData));

            if (millis() - lastDebugTime > 200) {
                lastDebugTime = millis();
                Serial.printf("[PIPELINE 10.4] S1:%.1f|S2:%.1f|S3:%.1f|S4:%.1f|S5:%.1f|KẸP:%s|ARM:%s\n", 
                               rawS2, rawS1, rawS3, rawS4, rawS5, isGripping?"ON":"OFF", isArmMoving?"MOVE":"STOP");
            }
        }
    }
}

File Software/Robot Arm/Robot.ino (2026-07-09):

#include <esp_now.h>
#include <WiFi.h>
#include <Wire.h>
#include <Adafruit_PWMServoDriver.h>

Adafruit_PWMServoDriver pwm = Adafruit_PWMServoDriver(0x40);

#define SERVO_FREQ 50 
#define SERVO_MIN  150 
#define SERVO_MAX  600 

const float MAX_SPEED = 2.0;
const float MAX_ACCEL = 0.12;

float currentAngles[6]     = {60.0, 60.0, 10.0, 90.0, 90.0, 10.0};
float currentVelocities[6] = {0.0, 0.0, 0.0, 0.0, 0.0, 0.0};
float targetAngles[6]      = {60.0, 60.0, 10.0, 90.0, 90.0, 10.0};

unsigned long lastServoUpdate = 0;

typedef struct { 
    float S1; float S2; float S3; float S4; float S5; float S6; 
} RobotCommand;

int angleToPWM(float angle) {
    angle = constrain(angle, 0.0, 180.0);
    return map((int)angle, 0, 180, SERVO_MIN, SERVO_MAX);
}

void OnDataRecv(const esp_now_recv_info_t *recv_info, const uint8_t *incomingData, int len) {
    RobotCommand incoming;
    memcpy(&incoming, incomingData, sizeof(incoming));
    targetAngles[0] = incoming.S1;
    targetAngles[1] = incoming.S2;
    targetAngles[2] = incoming.S3;
    targetAngles[3] = incoming.S4;
    targetAngles[4] = incoming.S5;
    targetAngles[5] = incoming.S6; 
}

void setup() {
    Serial.begin(115200);
    pwm.begin();
    pwm.setOscillatorFrequency(27000000);
    pwm.setPWMFreq(SERVO_FREQ);
    delay(10);
    for(int i = 0; i < 6; i++) {
        pwm.setPWM(i, 0, angleToPWM(currentAngles[i]));
    }
    WiFi.mode(WIFI_STA);
    Serial.print("DIA CHI MAC CUA ROBOT LA: ");
    Serial.println(WiFi.macAddress()); 
    if (esp_now_init() != ESP_OK) {
        Serial.println("Loi khoi tao ESP-NOW!");
        return;
    }
    esp_now_register_recv_cb(OnDataRecv);
    Serial.println("Bo dieu toc va gia toc Profiled-Control da san sang!");
}

void loop() {
    if (millis() - lastServoUpdate >= 20) {
        lastServoUpdate = millis();
        for (int i = 0; i < 6; i++) {
            float diff = targetAngles[i] - currentAngles[i];
            float desiredVelocity = diff * 0.15;
            float speedLimit = (i == 5) ? (MAX_SPEED * 1.5) : MAX_SPEED;
            desiredVelocity = constrain(desiredVelocity, -speedLimit, speedLimit);
            float velDiff = desiredVelocity - currentVelocities[i];
            float accelLimit = (i == 5) ? (MAX_ACCEL * 1.5) : MAX_ACCEL;
            velDiff = constrain(velDiff, -accelLimit, accelLimit);
            currentVelocities[i] += velDiff;
            currentAngles[i]     += currentVelocities[i];
            pwm.setPWM(i, 0, angleToPWM(currentAngles[i]));
        }
    }
}

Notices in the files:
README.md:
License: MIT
